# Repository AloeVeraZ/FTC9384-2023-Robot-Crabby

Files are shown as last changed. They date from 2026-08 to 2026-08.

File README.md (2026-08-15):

<div align="center">

# Crabby · FTC 9384 Competition Robot

### FTC Team 9384 Hydraulic Hydras · 2022–2023 POWERPLAY Season Robot CAD







<picture>
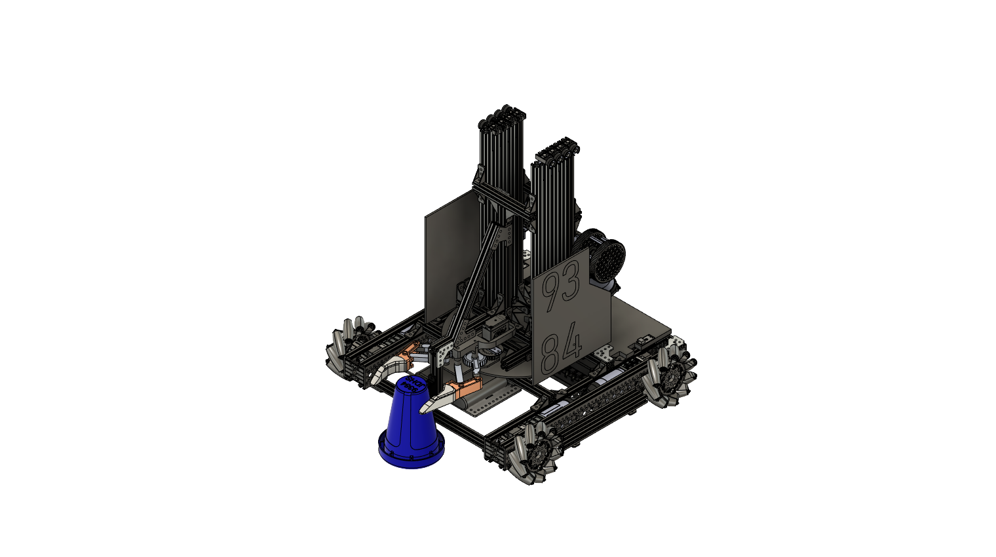
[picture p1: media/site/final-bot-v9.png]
CAD render of Crabby, FTC Team 9384's POWERPLAY robot
  
</picture>

Open mechanical design solid models, competition photography, design history, and subsystem CAD for FTC Team 9384's POWERPLAY robot.

<strong>Quick navigation:</strong><br>
[Robot Overview](#overview) | [Design History](docs/design-history.md) | [CAD Files](#cad-files) | [Competition Gallery](#project-media) | [GrabCAD Model](https://grabcad.com/library/ftc-9384-2022-2023-robot-1)

</div>

---

## Overview

**Crabby** was FTC Team 9384 Hydraulic Hydras' official competition robot for the 2022–2023 **POWERPLAY** season. Across three major competition iterations, the team developed an omnidirectional Mecanum drive base, dual cascading linear slide lift, compliant cone claw, and a compact direct-drive coaxial turret.

The defining mechanical innovation was the directly driven turret: placing the drive motor output shaft concentric with the center of turret rotation allowed the scoring lift and claw to aim at junction poles independently from chassis orientation, drastically reducing cycle times.

| Subsystem Specification | Technical Implementation |
| --- | --- |
| Drivetrain architecture | 4-wheel independent Mecanum drive with bevel gear wheel pods |
| Turret mechanism | Concentric direct-drive motor axis with large-diameter ring bearing |
| Vertical lift | Dual cascading REV linear slides with high-speed pulley rigging |
| End-effector claw | Active compliant servo gripper with conical wedge retention |
| Structural frame | Custom CNC machined aluminum plates and reinforced structural standoffs |
| Iteration milestones | 3 competition versions documented from Kickoff to State Championship |

## The Challenge

In the [POWERPLAY](https://www.youtube.com/watch?v=HsitvZ0JaDc) game, robots collected conical game elements and stacked them on vertical junction poles of varying heights (Low, Medium, High). Crabby was engineered to satisfy strict competition constraints:
- Full 3-DOF planar mobility to maneuver around dense junction forests.
- 33+ inch vertical reach to cap high junction goals.
- Rapid 360° turret targeting to score without rotating the drivetrain.

## Mechanical Evolution

| Phase | Competition Milestones | Mechanical Evolution |
| :---: | --- | --- |
| **Stage 1** | Kickoff to Qualifier 4 | H-frame Mecanum chassis, single REV linear slide, and two-servo compliant wheel intake. |
| **Stage 2** | Qualifier 4 to Super Qualifier | High-speed slide drive gearing, revised pinch claw, and concentric direct-drive turret. |
| **Stage 3** | Super Qualifier to State Championship | Dual-slide reinforced mast, enlarged turret bearing, bevel drivetrain, and lowered center of gravity. |

Read the in-depth mechanism failure mode analysis in [`docs/design-history.md`](docs/design-history.md).

## Project Media

<div align="center">

| Crabby Scoring on High Junction | Driving in Competition Traffic |
| :---: | :---: |
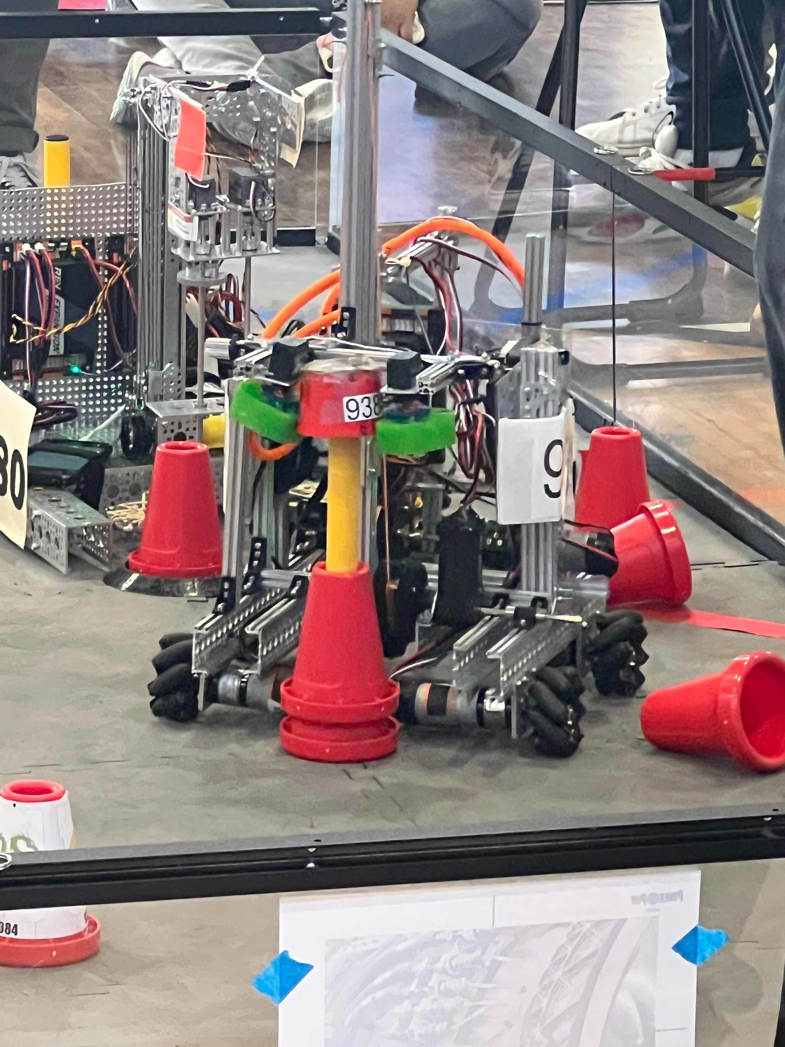
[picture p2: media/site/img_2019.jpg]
Crabby scoring a cone on a junction
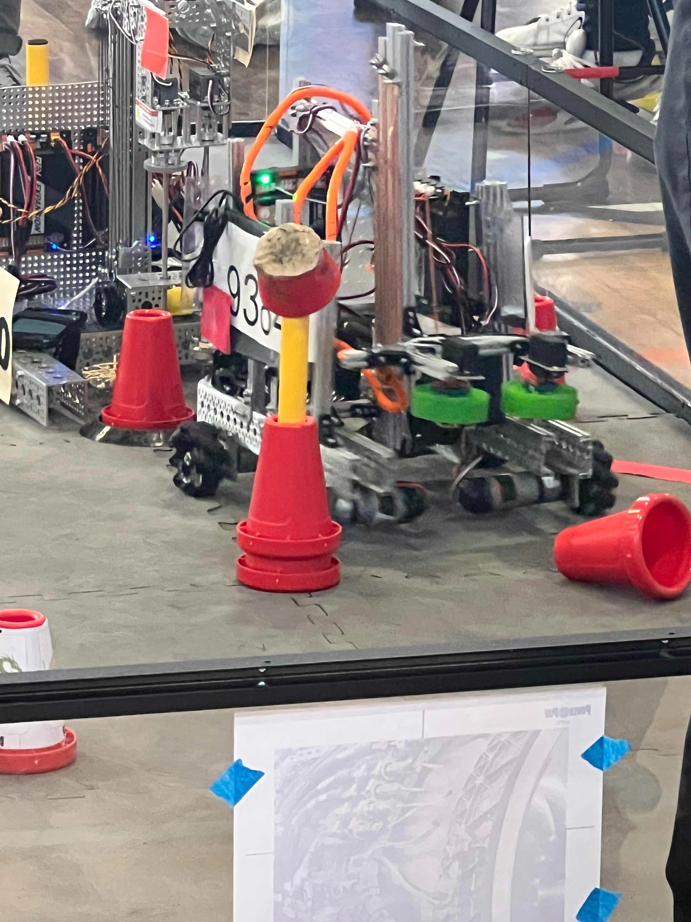
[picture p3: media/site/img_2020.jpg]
Crabby driving near a junction during competition
|  |  |

</div>

<div align="center">

| Pit Fabrication & Tuning | Concentric Direct-Drive Turret |
| :---: | :---: |
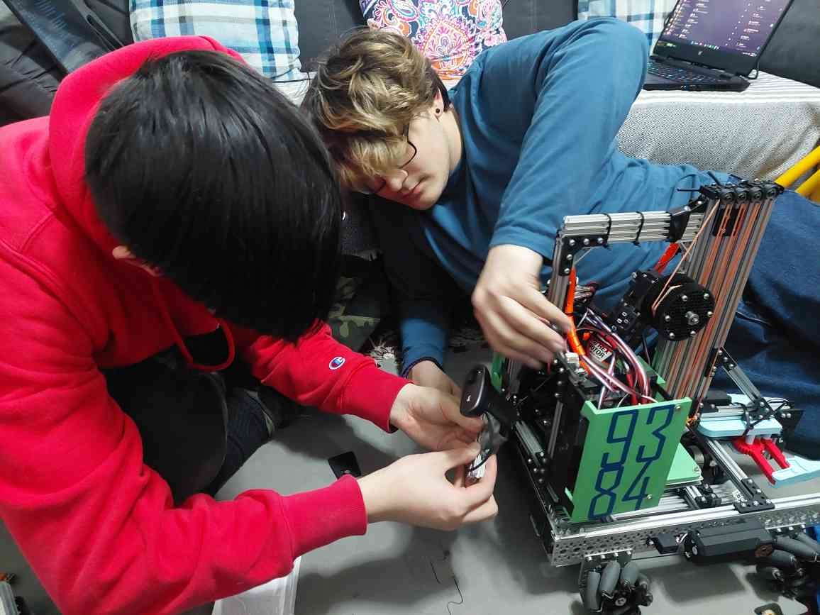
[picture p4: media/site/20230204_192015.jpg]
Team members working on Crabby
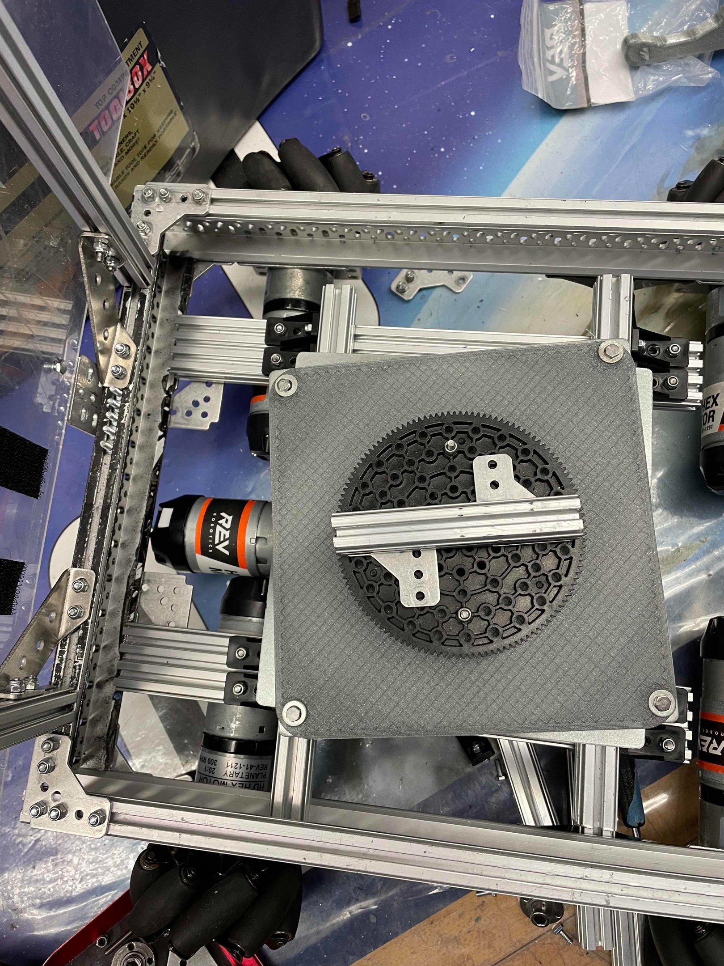
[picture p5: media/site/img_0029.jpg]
Top view of Crabby's direct-drive turret
|  |  |

</div>

<div align="center">

| Compliant Cone Claw CAD | Completed Competition Robot |
| :---: | :---: |
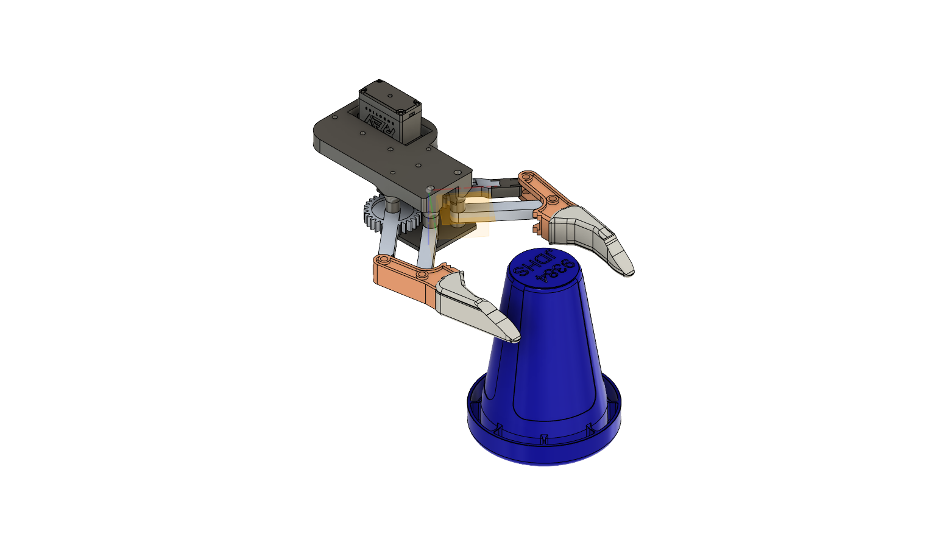
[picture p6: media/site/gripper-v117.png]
CAD render of Crabby's cone claw
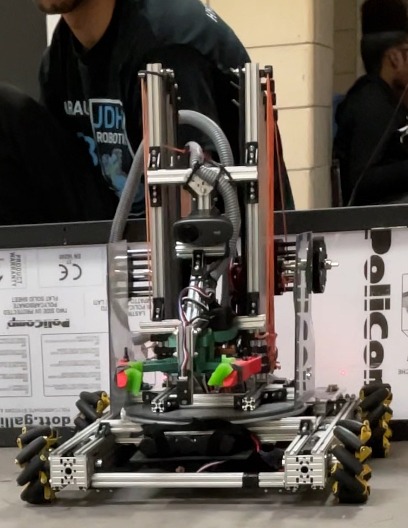
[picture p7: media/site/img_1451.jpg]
Front view of the completed Crabby robot
|  |  |

</div>

## CAD Files

Neutral ISO 10303 STEP exports compatible with Fusion 360, Onshape, SolidWorks, and Inventor:

| Subsystem File | Contents & Assemblies |
| --- | --- |
| [`final bot.step`](cad/final%20bot.step) | Master robot competition assembly |
| [`Chassis.step`](cad/Chassis.step) | Mecanum drive base and chassis frame |
| [`intake.step`](cad/intake.step) | Compliant cone intake and gripper |
| [`regular lifts.step`](cad/regular%20lifts.step) | Primary linear slide lift stage |
| [`inverted lift.step`](cad/inverted%20lift.step) | Inverted auxiliary slide rigging |
| [`turret assembled.step`](cad/turret%20assembled.step) | Concentric direct-drive turret assembly |

> [!NOTE]
> Large assembly files are tracked via Git LFS. Run `git lfs install && git lfs pull` after cloning.

## License & Attribution

Original CAD models, photographs, and documentation © 2022–2026 **Angelo Demetroulakos**. Licensed under the **[Creative Commons Attribution 4.0 International License](LICENSE)**.

```text
Based on the FTC 9384 2022–2023 Robot (Crabby) by Angelo Demetroulakos and FTC Team 9384 Hydraulic Hydras,
licensed under CC BY 4.0. Source: https://github.com/AloeVeraZ/FTC9384-2023-Robot-Crabby
```

---

<div align="center">

Built by **FTC Team 9384 · Hydraulic Hydras**

</div>

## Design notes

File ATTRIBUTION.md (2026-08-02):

# Attribution guide

Copyright © 2022-2026 Angelo Demetroulakos.

The Crabby robot project is licensed under the Creative Commons Attribution 4.0 International License (CC BY 4.0). You can copy, modify, redistribute, manufacture from, and use the project commercially, provided that you give appropriate credit.

## Recommended credit

Use this credit line when sharing an unmodified copy:

> Crabby (FTC Team 9384's 2022-2023 POWERPLAY robot) by Angelo Demetroulakos, licensed under CC BY 4.0. Source: https://github.com/AloeVeraZ/FTC9384-2023-Robot-Crabby

For a modified version, use:

> Based on Crabby by Angelo Demetroulakos, licensed under CC BY 4.0. Source: https://github.com/AloeVeraZ/FTC9384-2023-Robot-Crabby. Changes: [briefly describe your changes].

## What your credit needs to include

- **Creator:** Angelo Demetroulakos
- **Project:** Crabby - FTC Team 9384's 2022-2023 POWERPLAY robot
- **Source:** https://github.com/AloeVeraZ/FTC9384-2023-Robot-Crabby
- **License:** CC BY 4.0 - https://creativecommons.org/licenses/by/4.0/
- **Changes:** Say whether and how you modified the material

Credit may be placed wherever attribution is normally shown for the medium: a README, project page, video description, documentation, display card, credits screen, or another reasonably visible location.

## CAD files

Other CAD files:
cad/turret assembled.step
cad/Chassis.step
cad/final bot.step
cad/inverted lift.step
cad/intake.step
cad/regular lifts.step

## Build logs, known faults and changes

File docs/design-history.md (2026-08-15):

# Crabby design history

Crabby was built by FTC Team 9384, the Hydraulic Hydras, for the 2022-2023 POWERPLAY season. Work began at kickoff on September 10, 2022. The game rewarded teams for placing cones on junction poles of different heights and in designated field areas, with additional end-of-match bonuses. That challenge shaped every major mechanism on the robot.

The team produced three major robot iterations between kickoff and the State Championship. Each revision responded to a specific limitation observed during building or competition.

## Iteration 1: kickoff to Qualifier 4

### Linear slide

The first robot used a single [REV Robotics linear slide kit](https://www.revrobotics.com/rev-45-1507/) to reach the field's elevated scoring positions. The intake was attached to the bottom of the slide's final stage. The mechanism provided the needed reach, but the tall single-slide structure swayed when fully extended and the chassis moved. That motion could cause the robot to drop its cone.

### Chassis

The initial drive base used mecanum wheels for omnidirectional movement. Motors were mounted to aluminum C-channels with metal L-brackets, while the channels formed an H-shaped frame to keep the chassis square. The layout was based on the [REV Robotics Mecanum Drivetrain Kit](https://docs.revrobotics.com/duo-build/mecanum-drivetrain-kit-mecanum-drivetrain), with the remaining mechanisms bolted to the completed base.

### Intake

The original intake placed two compliant wheels on two servos with a narrow gap between them. A centered cone could be pulled in smoothly and held between the wheels, but the design did not reliably keep every cone upright or prevent it from falling out.

<p>
  First competition version of Crabby at a junction
  Crabby maneuvering around cones and junctions
</p>

## Iteration 2: Qualifier 4 to Super Qualifier

### Faster lift

The slide structure remained mostly unchanged, but its motor gearing was revised to increase lifting speed and shorten the scoring cycle.

### Claw intake

Because the compliant-wheel intake could not consistently keep cones upright, the team replaced it with a claw. The claw proved much more reliable for the robot's scoring workflow.

CAD render of the revised cone claw

### Direct-drive turret

The fixed lift forced the drivetrain to face a junction before scoring. To remove that alignment step, the team mounted the lift on a turret driven directly through the center of its lazy Susan bearing. The motor shaft occupied the turret's central axis, allowing the scoring assembly to rotate independently from the chassis. The team was not aware of an earlier FTC robot using this same direct-drive arrangement.

Top view of the turret's central drive and bearing

## Iteration 3: Super Qualifier to State Championship

### Dual slides and larger turret

A second linear slide was added to square the lift and reduce sway at maximum extension. The turret's small lazy Susan bearing was replaced with a larger one, providing enough support and surface area for both slides.

### Lower, stronger drivetrain

The chassis was substantially redesigned. Four 90-degree bevel gearboxes moved the drive motors inside the existing C-channels instead of pointing them toward the center of the robot. This placed the wheel axes through the channels' center openings and allowed a lower chassis. Additional cross-members distributed loads and kept the enlarged turret base square.

### Final intake

The claw from the second iteration was retained because it had solved the cone-retention problem.

<p>
  Team members servicing the revised robot
  Front view of final Crabby configuration
</p>

## Final configuration

The completed robot combined:

- A low, braced mecanum chassis.
- Four drive motors packaged inside the C-channels through bevel gearboxes.
- Two linear slides for reach and rigidity.
- A claw-style cone intake.
- A larger lazy Susan bearing.
- A compact, directly driven turret for chassis-independent aiming.

Final CAD rendering of Crabby

[Watch Crabby in competition](../media/site/crabby-match-video.mp4).

## Sources

- [Repository project overview](../README.md)
- [FTC 2022-2023 POWERPLAY game animation](https://www.youtube.com/watch?v=HsitvZ0JaDc)
- [Original GrabCAD model listing](https://grabcad.com/library/ftc-9384-2022-2023-robot-1)
